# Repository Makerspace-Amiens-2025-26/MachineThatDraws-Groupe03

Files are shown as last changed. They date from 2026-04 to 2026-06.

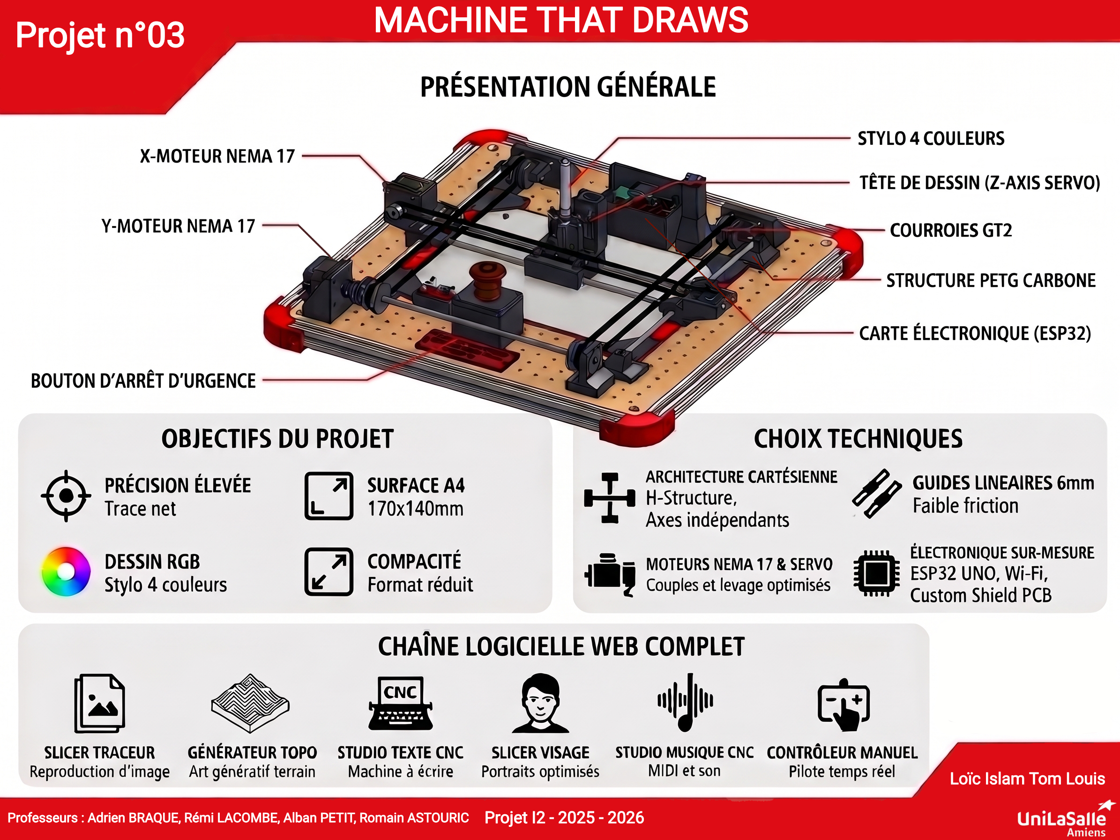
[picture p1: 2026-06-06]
docs/assets/img/poster.png

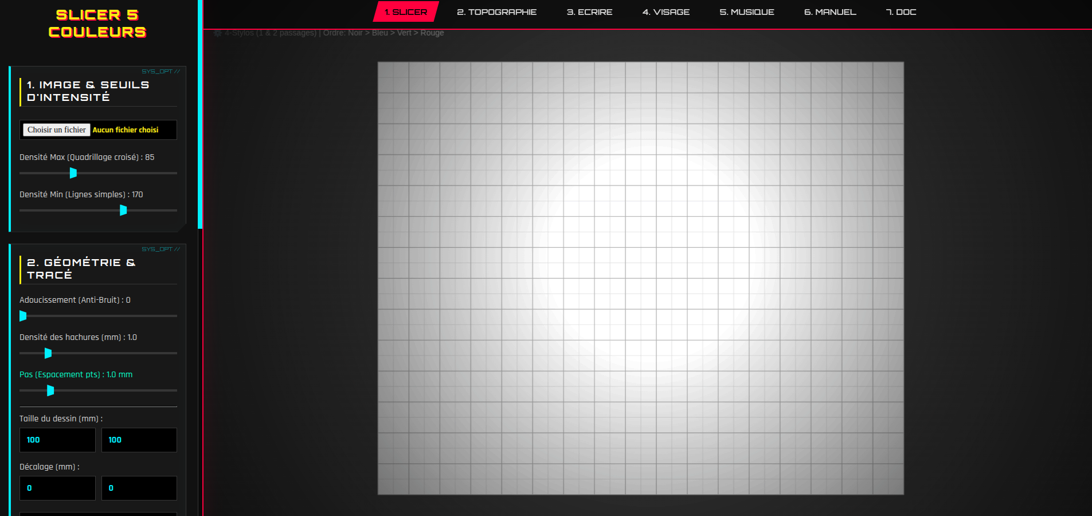
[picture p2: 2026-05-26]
docs/assets/img/interface1.png

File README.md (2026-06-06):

# 🤖 MachineThatDraws

**MachineThatDraws** est un traceur vectoriel automatisé (stylo sur papier) conçu de A à Z par le Groupe 3 constituer de Loïc Islam Louis et Tom. Capable de dessiner sur une surface utile de **170x140 mm**, cette machine se distingue par une indépendance logicielle totale : **toute la chaîne de contrôle et de génération de G-Code est gérée directement depuis un navigateur Web**, sans nécessiter l'installation de logiciels tiers.

---

##  Fonctionnalités Principales

-  **100% Web & Plug-and-Play :** Contrôle direct de la machine via le navigateur Chrome grâce à l'API **Web Serial**.
-  **Électronique Sur-Mesure :** Remplacement des solutions génériques par un microcontrôleur **ESP32 UNO** couplé à un **PCB "Fait Maison"** pour la puissance.
-  **Tête Hybride & Dessin Multicouleur :** Mouvement vertical (Axe Z) géré par un servomoteur et un système d'élastiques pour une pression constante. Supporte l'utilisation d'un stylo 4 couleurs (pauses automatiques pour changement manuel).
-  **Mécanique Fluide :** Guidage par tiges en acier de 6mm et bagues imprimées en **PETG-PTFE** (auto-lubrifiantes) pour un silence et une fluidité absolus.

---

##  Matériel & Ingénierie (Hardware)

### Architecture Cartésienne
La machine utilise une architecture en H (Axes X et Y indépendants) pour maximiser la rigidité, la précision géométrique et simplifier les calculs du firmware.
- **Moteurs :** NEMA 17 pour les axes X et Y (couple élevé, zéro perte de pas).
- **Axe Z :** Servomoteur ultra-léger (levée de 7 mm).
- **Transmission :** Courroies GT2 avec tendeurs micrométriques intégrés aux pièces 3D.
- **Impression 3D :** Pièces mécaniques imprimées en **PETG-CF** et **PLA-CF** (chargés en fibre de carbone) pour la rigidité structurelle. Assemblage robuste via des inserts filetés M3 en laiton.

### Électronique
- **Cerveau :** ESP32 UNO flashé avec le firmware **FluidNC** (évolution de GRBL).
- **Shield Maison :** PCB double couche routé spécifiquement pour le projet. Séparation stricte de la logique (5V/USB) et de la puissance (12V externe).
- **Sécurité :** Bouton d'Arrêt d'Urgence (BAU) et capteurs de fin de course (Endstops) mécaniques matériels avec offset de sécurité (5mm).

---

##  Suite Logicielle (Software)

L'équipe a fait le choix radical de coder ses propres "Slicers" et interfaces en **HTML, CSS et JavaScript pur**. La suite est divisée en 5 modules distincts :

### 1. Slicer Traceur (Reproduction d'Images)
Convertit n'importe quelle image matricielle (JPEG/PNG) en G-Code vectoriel. 
- Algorithme à **3 zones (Noir/Gris/Blanc)** : hachures croisées pour les zones sombres, lignes simples pour les zones grises, et épargne du papier pour les zones claires.
- Optimisation du chemin via l'algorithme du voyageur de commerce (TSP nearest neighbor).

### 2. Générateur Topographique (Art Génératif)
Crée des paysages uniques en temps réel en utilisant le **bruit de Perlin** (via `p5.js`).
- Tracé optimisé en zigzag pour éviter de lever le stylo.
- Filtrage intelligent des points superflus pour alléger le fichier G-Code.

### 3. Studio Texte CNC (Word Vectoriel)
Transforme la CNC en machine à écrire. Un véritable éditeur multi-calques qui utilise la fonction `textToPoints` pour convertir des polices TTF en coordonnées (X, Y) traçables par le stylo. Gère l'inclinaison par rotation trigonométrique.

### 4. Slicer Visage (Algorithme "Squiggle")
Un algorithme spécifique pour le portrait. Simule les ombres d'un visage en modulant l'amplitude et la fréquence d'une **onde sinusoïdale** continue, créant un effet de gravure organique.

### 5. Studio Musique CNC (Lecteur MIDI)
Détourne la fonction première de la machine pour lui faire jouer de la musique ! Convertit des fichiers `.mid` en fréquences de rotation pour faire "chanter" les moteurs pas-à-pas tout en gérant un algorithme de rebond balistique pour rester dans les limites du plateau.

### 6. Manuel
Il permet de contrôler la machine manuellement avec les flèches du clavier et la barre d'espace. Grâce à lui, nous pouvons régler la vitesse idéale pour la machine.

---

##  Comment l'utiliser ?

1. **Branchement :** Reliez l'alimentation 12V au boîtier et connectez le câble USB à votre PC.
2. **Interface :** Ouvrez l'interface Web (fichiers HTML) dans un navigateur compatible Web Serial (ex: Google Chrome).
3. **Connexion :** Cliquez sur "Connecter USB" et sélectionnez le port série de l'ESP32 (BaudRate : 115200).
4. **Initialisation :** Lancez la procédure de *Homing* (`$H`) pour que la machine trouve son point 0,0 via les endstops.
5. **Génération & Dessin :** Choisissez un des 5 modules, paramétrez votre création en temps réel sur le canvas, puis cliquez sur "Lancer l'impression" !

---

## 👥 Équipe & Crédits

- Projet réalisé par le **Groupe 3** constituer de Loïc Islam Louis et Tom dans le cadre d'un projet académique.
- **Librairies utilisées :** `p5.js` (rendu canvas et mathématiques), `imagetracer.js` (vectorisation), `@tonejs/midi` (parsing musical).

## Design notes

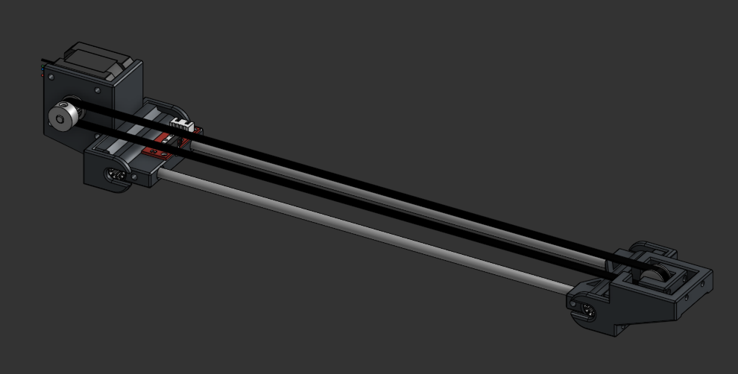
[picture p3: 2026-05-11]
docs/assets/img/X.png

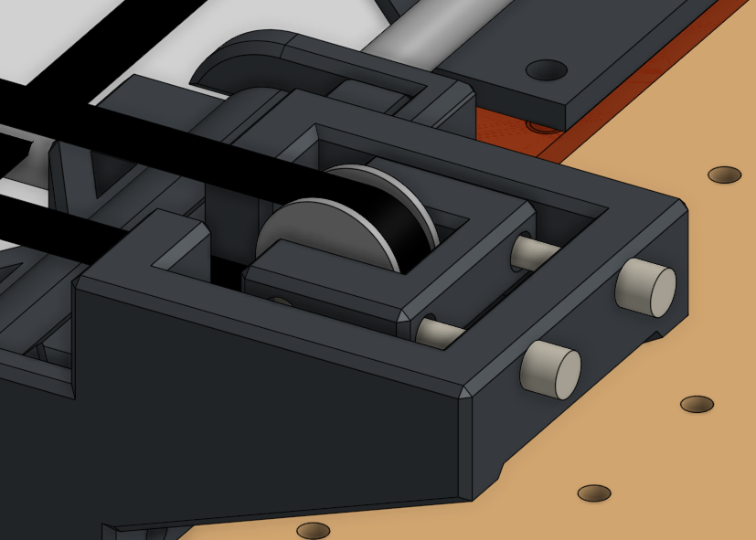
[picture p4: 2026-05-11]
docs/assets/img/visse.png

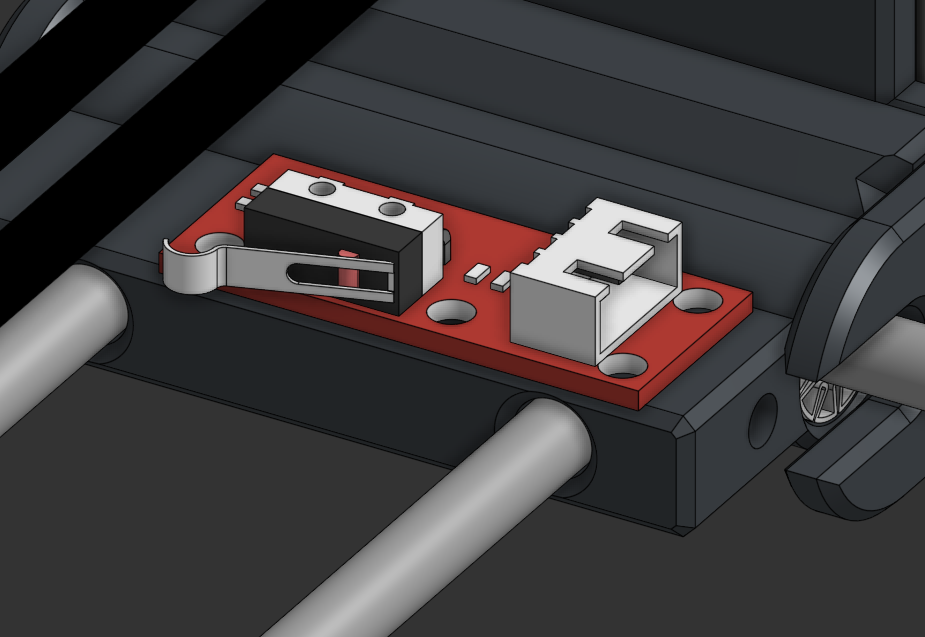
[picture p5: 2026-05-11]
docs/assets/img/capteur2.png

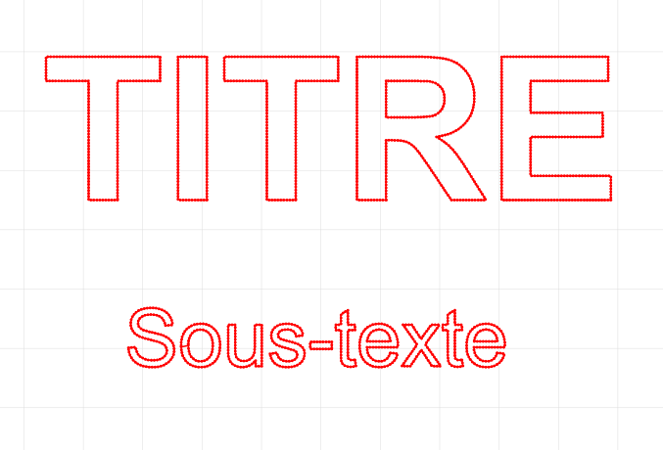
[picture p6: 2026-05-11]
docs/assets/img/slicer3.png

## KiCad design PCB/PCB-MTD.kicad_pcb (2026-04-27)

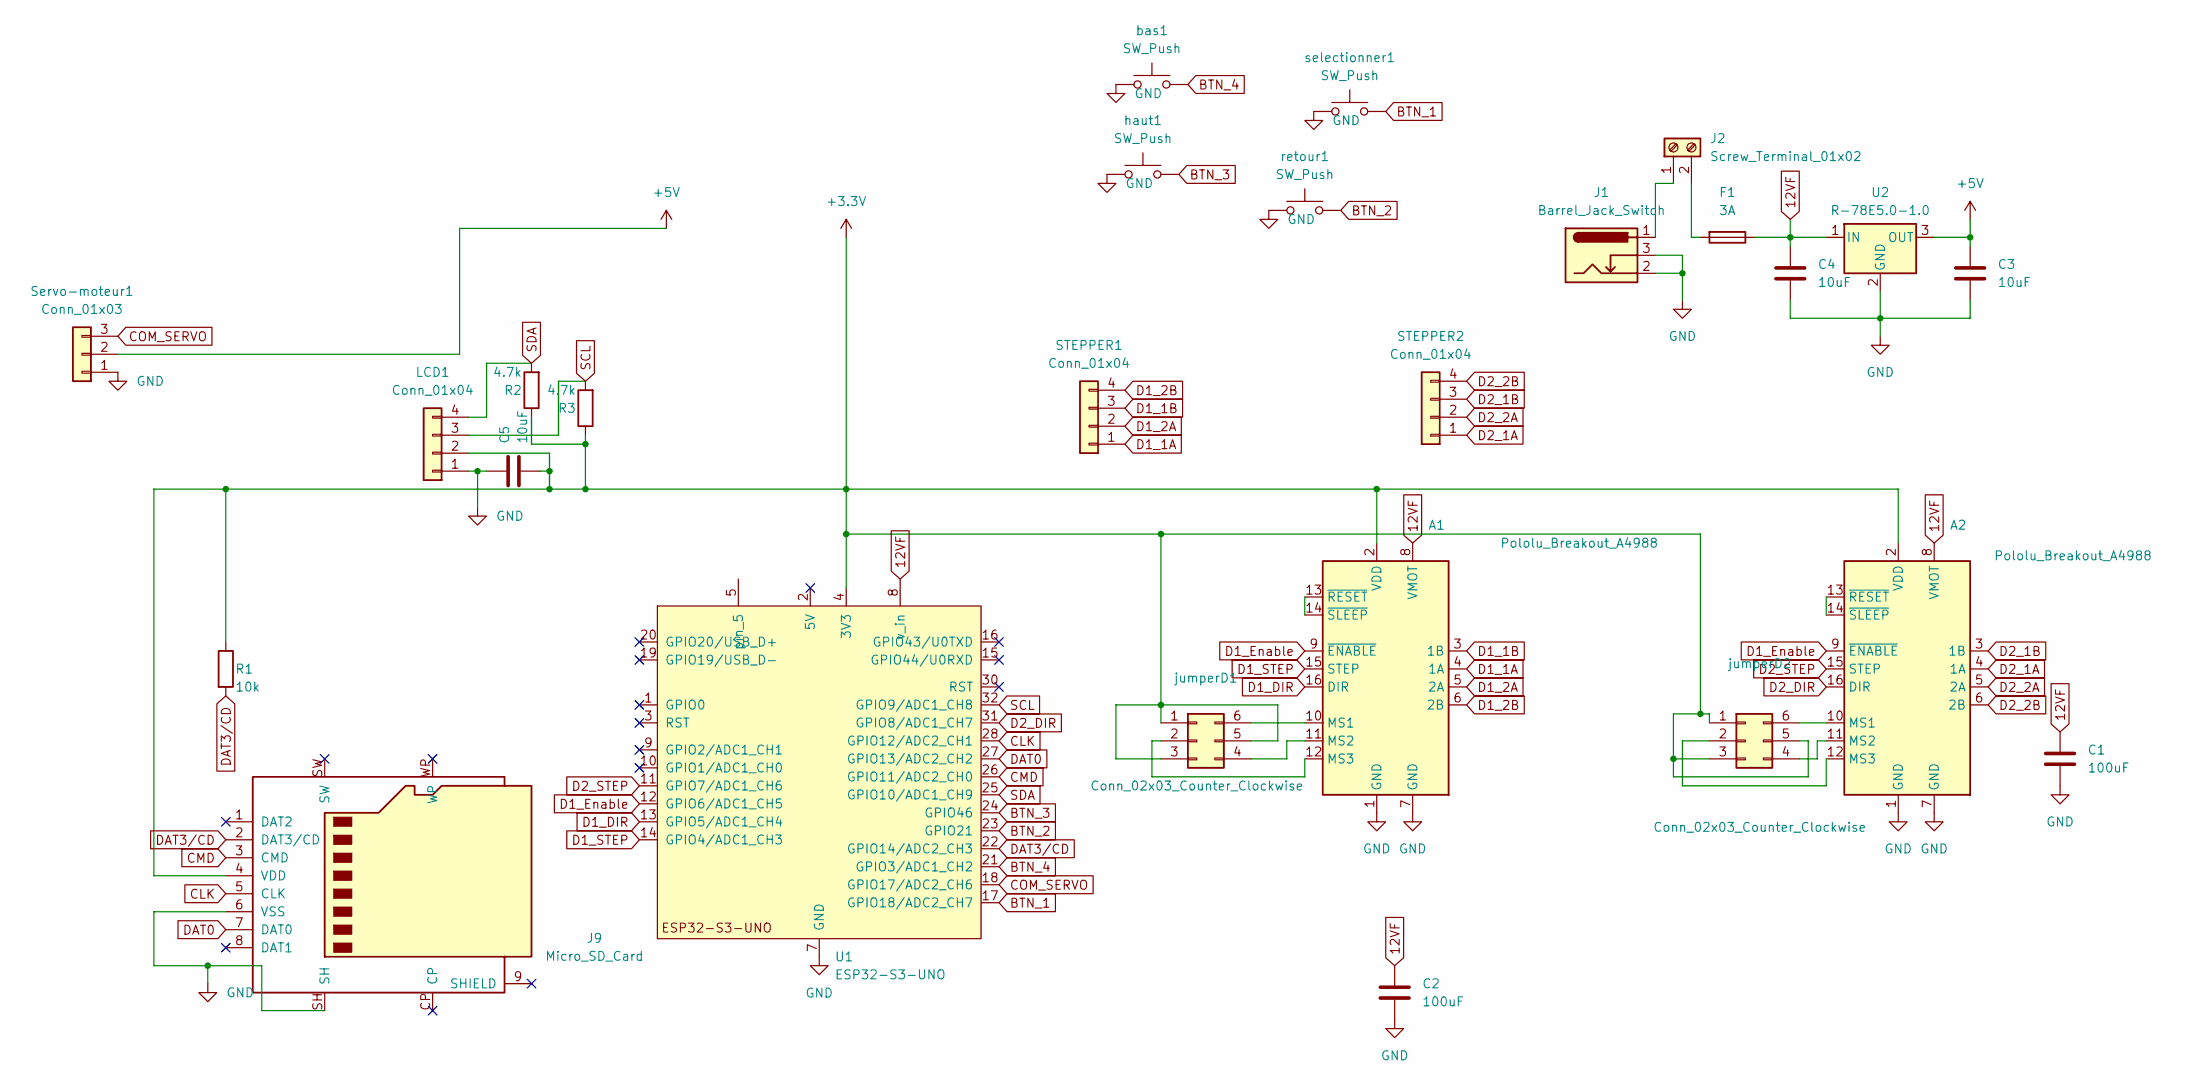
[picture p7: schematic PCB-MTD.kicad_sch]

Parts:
A1, A2: Pololu_Breakout_A4988; Pololu_Breakout-16_15.2x20.3mm
C1, C2: 100uF; CP_Elec_6.3x5.4
C3, C4, C5: 10uF; C_1206_3216Metric_Pad1.33x1.80mm_HandSolder
F1: 3A; Fuseholder_Blade_Mini_Keystone_3568
J1: Barrel_Jack_Switch; BarrelJack_Horizontal
J2: Screw_Terminal_01x02; TerminalBlock_Phoenix_MKDS-1,5-2-5.08_1x02_P5.08mm_Horizont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
J9: Micro_SD_Card; SD_Hirose_DM1AA_SF_PEJ82
LCD1: Conn_01x04; PinHeader_1x04_P2.54mm_Vertical
R1: 10k; R_0805_2012Metric_Pad1.20x1.40mm_HandSolder
R2, R3: 4.7k; R_0805_2012Metric_Pad1.20x1.40mm_HandSolder
STEPPER1, STEPPER2: Conn_01x04; PinHeader_1x04_P2.54mm_Vertical
Servo-moteur1: Conn_01x03; PinHeader_1x03_P2.54mm_Vertical
U1: ESP32-S3-UNO; ESP_S3_UNO
U2: R-78E5.0-1.0; Converter_DCDC_RECOM_R-78E-0.5_THT
bas1: SW_Push; SW_Tactile_Straight_KSA0Axx1LFTR
haut1: SW_Push; SW_Tactile_Straight_KSA0Axx1LFTR
jumperD1, jumperD2: Conn_02x03_Counter_Clockwise; PinHeader_2x03_P2.54mm_Vertical
retour1: SW_Push; SW_Tactile_Straight_KSA0Axx1LFTR
selectionner1: SW_Push; SW_Tactile_Straight_KSA0Axx1LFTR

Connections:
12VF: A1.8 (VMOT), A2.8 (VMOT), C1.1, C2.1, C4.1, F1.1, U1.8 (v_in), U2.1 (IN)
+3.3V: A1.2 (VDD), A2.2 (VDD), C5.2, J9.4 (VDD), LCD1.2, R1.1, R2.1, R3.1, U1.4 (3V3), jumperD1.1, jumperD1.3, jumperD1.5, jumperD2.1, jumperD2.3, jumperD2.5
+5V: C3.1, Servo-moteur1.2, U2.3 (OUT)
BTN_1: U1.17 (GPIO18/ADC2_CH7), selectionner1.2
BTN_2: U1.23 (GPIO21), retour1.2
BTN_3: U1.24 (GPIO46), haut1.2
BTN_4: U1.21 (GPIO3/ADC1_CH2), bas1.2
CLK: J9.5 (CLK), U1.28 (GPIO12/ADC2_CH1)
CMD: J9.3 (CMD), U1.26 (GPIO11/ADC2_CH0)
COM_SERVO: Servo-moteur1.3, U1.18 (GPIO17/ADC2_CH6)
D1_1A: A1.4 (1A), STEPPER1.1
D1_1B: A1.3 (1B), STEPPER1.3
D1_2A: A1.5 (2A), STEPPER1.2
D1_2B: A1.6 (2B), STEPPER1.4
D1_DIR: A1.16 (DIR), U1.13 (GPIO5/ADC1_CH4)
D1_Enable: A1.9 (~ENABLE), A2.9 (~ENABLE), U1.12 (GPIO6/ADC1_CH5)
D1_STEP: A1.15 (STEP), U1.14 (GPIO4/ADC1_CH3)
D2_1A: A2.4 (1A), STEPPER2.1
D2_1B: A2.3 (1B), STEPPER2.3
D2_2A: A2.5 (2A), STEPPER2.2
D2_2B: A2.6 (2B), STEPPER2.4
D2_DIR: A2.16 (DIR), U1.31 (GPIO8/ADC1_CH7)
D2_STEP: A2.15 (STEP), U1.11 (GPIO7/ADC1_CH6)
DAT0: J9.7 (DAT0), U1.27 (GPIO13/ADC2_CH2)
DAT3/CD: J9.2 (DAT3/CD), R1.2, U1.22 (GPIO14/ADC2_CH3)
GND: A1.1 (GND), A1.7 (GND), A2.1 (GND), A2.7 (GND), C1.2, C2.2, C3.2, C4.2, C5.1, J1.2, J1.3, J9.6 (VSS), J9.SH, LCD1.1, Servo-moteur1.1, U1.6 (GND), U1.7 (GND), U1.29 (GND), U2.2 (GND), bas1.1, haut1.1, retour1.1, selectionner1.1
unnamed: A1.10 (MS1), jumperD1.6
unnamed: A1.11 (MS2), jumperD1.4
unnamed: A1.12 (MS3), jumperD1.2
unnamed: A1.13 (~RESET), A1.14 (~SLEEP)
unnamed: A2.10 (MS1), jumperD2.6
unnamed: A2.11 (MS2), jumperD2.4
unnamed: A2.12 (MS3), jumperD2.2
unnamed: A2.13 (~RESET), A2.14 (~SLEEP)
unnamed: J1.1, J2.1
unnamed: F1.2, J2.2
SCL: LCD1.3, R3.2, U1.32 (GPIO9/ADC1_CH8)
SDA: LCD1.4, R2.2, U1.25 (GPIO10/ADC1_CH9)

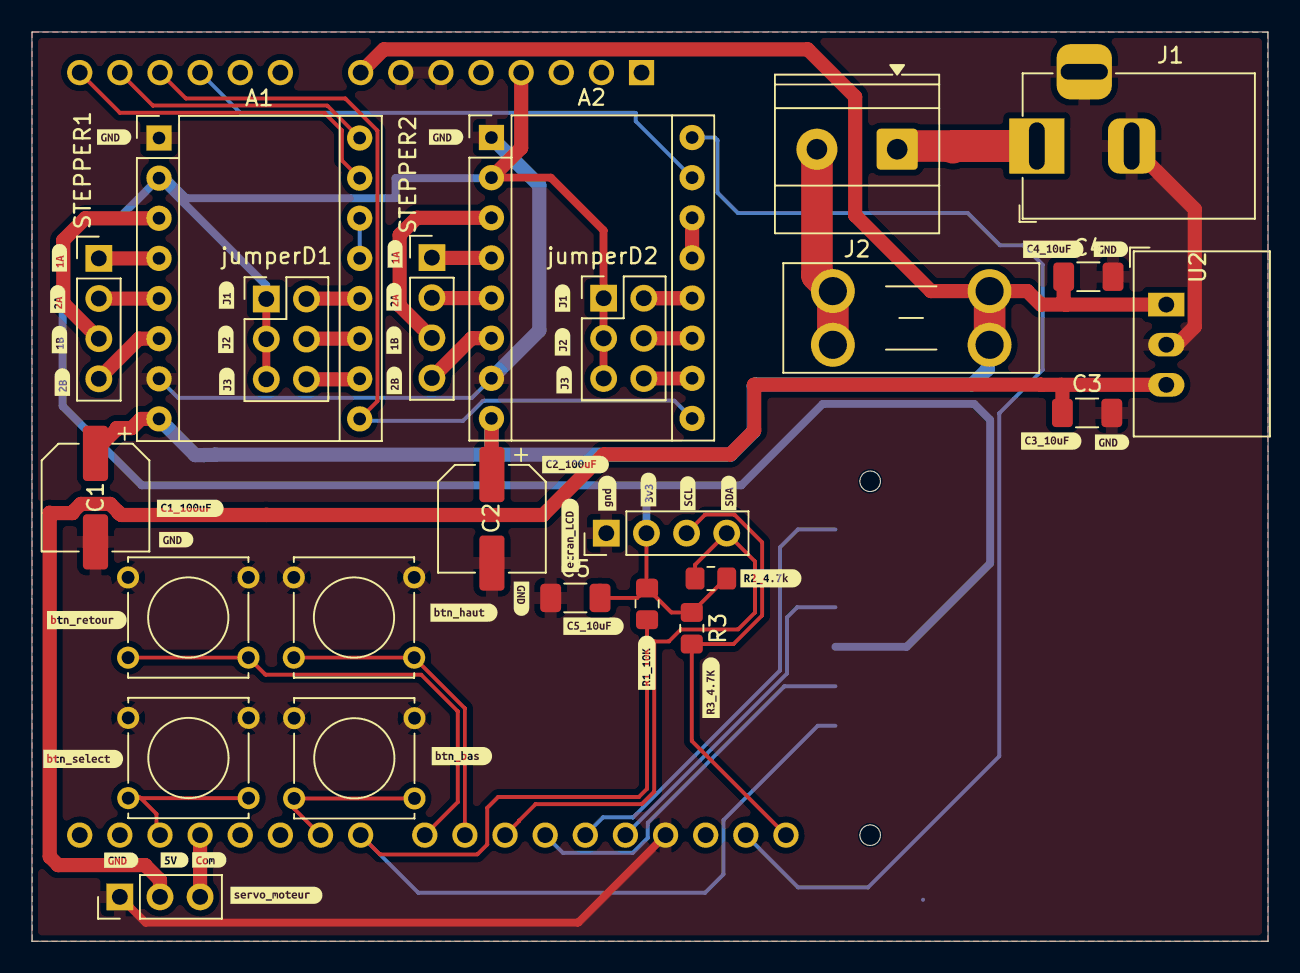
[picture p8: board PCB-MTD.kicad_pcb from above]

Board: 2 copper layers, 78.2 x 57.6 mm, 67 parts (1 on the bottom side), 38 nets.

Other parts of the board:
kibuzzard-69E8AB7B: G***; kibuzzard-69E8AB7B
kibuzzard-69E8AB48: G***; kibuzzard-69E8AB48
kibuzzard-69E8AB94: G***; kibuzzard-69E8AB94
kibuzzard-69E8ABA4: G***; kibuzzard-69E8ABA4
kibuzzard-69E8ABD2: G***; kibuzzard-69E8ABD2
kibuzzard-69E8ABED: G***; kibuzzard-69E8ABED
kibuzzard-69E8ABFE: G***; kibuzzard-69E8ABFE
kibuzzard-69E8AC2D: G***; kibuzzard-69E8AC2D
kibuzzard-69E8AC3C: G***; kibuzzard-69E8AC3C
kibuzzard-69E8AC9A: G***; kibuzzard-69E8AC9A
kibuzzard-69E8ACB2: G***; kibuzzard-69E8ACB2
kibuzzard-69E8ACC9: G***; kibuzzard-69E8ACC9
kibuzzard-69E8AD3B, kibuzzard-69E8AD3B#2: G***; kibuzzard-69E8AD3B
kibuzzard-69E8AD47, kibuzzard-69E8AD47#2: G***; kibuzzard-69E8AD47
kibuzzard-69E8AD54, kibuzzard-69E8AD54#2: G***; kibuzzard-69E8AD54
kibuzzard-69E8ADAF, kibuzzard-69E8ADAF#2: G***; kibuzzard-69E8ADAF
kibuzzard-69E8ADD5, kibuzzard-69E8ADD5#2: G***; kibuzzard-69E8ADD5
kibuzzard-69E8AE0E: G***; kibuzzard-69E8AE0E
kibuzzard-69E8AE4C: G***; kibuzzard-69E8AE4C
kibuzzard-69E8AE7F: G***; kibuzzard-69E8AE7F
kibuzzard-69E8AE60: G***; kibuzzard-69E8AE60
kibuzzard-69E8AE92: G***; kibuzzard-69E8AE92
kibuzzard-69E8AEC7: G***; kibuzzard-69E8AEC7
kibuzzard-69E8AEDA, kibuzzard-69E8AEDA#2: G***; kibuzzard-69E8AEDA
kibuzzard-69E8AEFD: G***; kibuzzard-69E8AEFD
kibuzzard-69E8AF1C: G***; kibuzzard-69E8AF1C
kibuzzard-69E8B027, kibuzzard-69E8B027#2: G***; kibuzzard-69E8B027
kibuzzard-69E8C7AB: G***; kibuzzard-69E8C7AB
kibuzzard-69E8C7B2: G***; kibuzzard-69E8C7B2
kibuzzard-69E8C7BE: G***; kibuzzard-69E8C7BE
kibuzzard-69E8C8E3: G***; kibuzzard-69E8C8E3
kibuzzard-69E8C83B: G***; kibuzzard-69E8C83B
kibuzzard-69E8C827: G***; kibuzzard-69E8C827
kibuzzard-69E8C830: G***; kibuzzard-69E8C830

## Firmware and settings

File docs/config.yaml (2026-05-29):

name: MachineThatsDrawsGroupe3_CustomPCB
stepping:
  engine: RMT
  idle_ms: 255
  pulse_us: 4
  dir_delay_us: 0
  disable_delay_us: 50
axes:
  
  shared_stepper_disable_pin: gpio.6
  homing_runs: 1
  x:
    steps_per_mm: 80
    max_rate_mm_per_min: 5000
    acceleration_mm_per_sec2: 2000
    max_travel_mm: 170
    motor0:
      limit_all_pin: NO_PIN
      limit_neg_pin: gpio.0:low:pu 
      limit_pos_pin: NO_PIN    
      hard_limits: false
      pulloff_mm: 6
      standard_stepper:
        step_pin: gpio.4
        direction_pin: gpio.5
        disable_pin: NO_PIN
    homing:
      cycle: 1
      mpos_mm: 170          
      positive_direction: false  
      seek_mm_per_min: 600
      feed_mm_per_min: 200
      settle_ms: 500
  y:
    steps_per_mm: 42
    max_rate_mm_per_min: 5000
    acceleration_mm_per_sec2: 2000
    max_travel_mm: 140
    motor0:
      limit_all_pin: NO_PIN
      limit_neg_pin: gpio.19:low:pu
      limit_pos_pin: NO_PIN
      hard_limits: false
      pulloff_mm: 6
      standard_stepper:
        step_pin: gpio.7
        direction_pin: gpio.8
        disable_pin: NO_PIN
    homing:
      cycle: 2
      mpos_mm: 140
      positive_direction: false
      seek_mm_per_min: 1000
      feed_mm_per_min: 200
      settle_ms: 250
  z:
    steps_per_mm: 100
    max_rate_mm_per_min: 5000
    acceleration_mm_per_sec2: 1000
    max_travel_mm: 5
    motor0:
      limit_all_pin: NO_PIN
      limit_neg_pin: NO_PIN
      limit_pos_pin: NO_PIN
      hard_limits: false
      pulloff_mm: 1
      rc_servo:
        output_pin: gpio.17

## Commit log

2026-04-10 PCB fait erreur corriger
    [PCB-MTD.kicad_pcb, PCB-MTD.kicad_sch]
2026-04-24 Validation PCB pour production
    Attention :
    - Incohérence alimentation Driver et Jumper microstepping
    - Resistance de tirage haut SCL SDA
2026-04-25 Test Html
    [PCB-MTD.kicad_pcb, PCB-MTD.kicad_sch]
2026-04-25 Suppression des actions Jekyll
2026-04-25 pcb clean
    [PCB-MTD.kicad_pcb, PCB-MTD.kicad_sch]
2026-04-27 fix wiring problems
    [PCB-MTD.kicad_pcb, PCB-MTD.kicad_sch]
2026-05-20 ajoute reprise, optimisation et importation de gcode
2026-05-20 clean fichiers pcb
2026-05-21 fix pour reprise coupure courant + ajout yaml fluid nc
    [fluidnc.yaml]
